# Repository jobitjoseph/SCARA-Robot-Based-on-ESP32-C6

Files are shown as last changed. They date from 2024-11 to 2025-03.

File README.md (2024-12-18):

# [DIY Scara Robot Based on RISC-V Architecture](https://circuitdigest.com/videos/scara-robotic-arm-using-esp32)
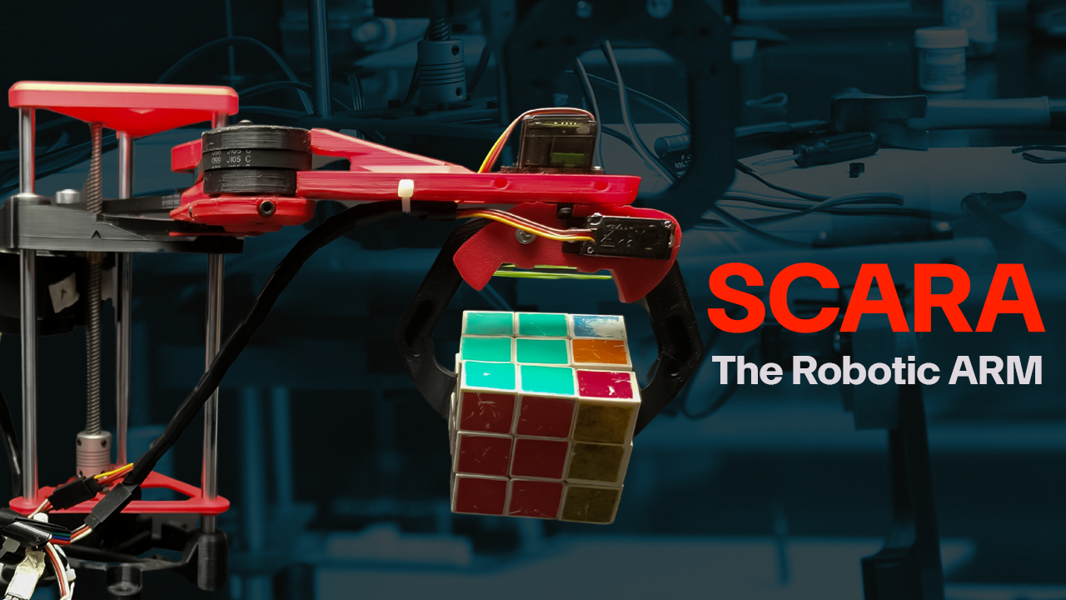
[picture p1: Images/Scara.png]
image_tooltip

<br>
A DIY SCARA (Selective Compliance Assembly Robot Arm) robot is a versatile, compact robotic arm designed for tasks requiring precision, such as assembly, sorting, and pick-and-place operations. As robotics becomes integral to modern industry and education, SCARA robots offer a practical and accessible way to explore automation, robotics programming, and motion control. This project combines affordability with high functionality, making it a valuable tool for learning and small-scale automation.
At the heart of the robot lies the ESP32-C6 WROOM module, a powerful microcontroller equipped with Wi-Fi and Bluetooth capabilities, ensuring seamless connectivity and control. The robot's motion is driven by NEMA 17 stepper motors, powered by TMC2209 drivers known for their smooth and efficient operation. Two SG90S servo motors handle the gripper, enabling precise manipulation of objects. The robot’s electronics are powered by a robust power system, featuring an LM2596-5 buck converter to step down a wide input voltage to 5V. This 5V rail is further regulated to 3.3V by an ADP7118AUJZ-3.3 low-noise CMOS LDO from Analog Devices, providing stable power to the ESP32-C6. Analog Devices’s MAX6899 supervisor IC ensures reliable boot-up of the system, while an onboard RGB LED offers visual feedback for status indications. The SCARA robot connects to a computer via a USB Type-C port, leveraging the ESP32-C6's native USB interface for streamlined communication. Control software, written in Python, provides an intuitive interface to operate the robot, featuring functions like direct control and a record-and-playback mode. This functionality allows users to program complex movements by recording and replaying actions with precision. The robot’s firmware is developed using the Arduino IDE, enabling customization and further development by hobbyists and professionals alike.

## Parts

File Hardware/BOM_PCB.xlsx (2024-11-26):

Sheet: Sheet1
Value | Footprint | Quantity | Manufacturer | Manufacturer Product Number | DigiKey Part Number | DigiKey Link
7pf | 0603 | 4 | Samsung Electro-Mechanics | CL10C070CB8NNNC | 1276-2137-1-ND | https://www.digikey.in/en/products/detail/samsung-electro-mechanics/CL10C070CB8NNNC/3887795
SDT30B100D1-13 | TO252_DIO | 2 | Diodes Incorporated | SDT30B100D1-13 | SDT30B100D1-13DICT-ND | https://www.digikey.in/en/products/detail/diodes-incorporated/SDT30B100D1-13/7667006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
ADP7118AUJZ-3.3-R7 | SOT95P280X100-5N | 4 | Analog Devices | ADP7118AUJZ-3.3-R7 | 505-ADP7118AUJZ-3.3-R7CT-ND | https://www.digikey.in/en/products/detail/analog-devices-inc/ADP7118AUJZ-3-3-R7/5056890
INA236BIDDFR | SOT65P280X110-8N | 2 | Texas Instruments | INA236BIDDFR | 296-INA236BIDDFRCT-ND | https://www.digikey.in/en/products/detail/texas-instruments/INA236BIDDFR/21298612
MCP6486T-E_OT | SOT95P280X145-5N | 2 | Microchip Technology | MCP6486T-E/OT | 150-MCP6486T-E/OTCT-ND | https://www.digikey.in/en/products/detail/microchip-technology/MCP6486T-E-OT/16623982
SP485REN-L_TR | SOIC127P600X175-8N | 2 | MaxLinear, Inc. | SP485REN-L/TR | 1016-SP485REN-L/TRCT-ND | https://www.digikey.in/en/products/detail/maxlinear-inc/SP485REN-L-TR/2471965
NTC 100K | NTC | 2 | Eaton - Electronics Division | NRSE105H3950B1H | 283-NRSE105H3950B1H-ND | https://www.digikey.in/en/products/detail/eaton-electronics-division/NRSE105H3950B1H/16909364
909R | 0603 | 4 | Panasonic Electronic Components | ERA-3AEB9090V | P909DBCT-ND | https://www.digikey.in/en/products/detail/panasonic-electronic-components/ERA-3AEB9090V/2026745
100R | 0603 | 4 | YAGEO | RT0603BRD07100RL | YAG1497CT-ND | https://www.digikey.in/en/products/detail/yageo/RT0603BRD07100RL/1072188
.1 10W | WSHP2818R1000FEB | 8 | Vishay Dale | WSHP2818R1000FEB | 541-WSHP2818R1000FEBCT-ND | https://www.digikey.in/en/products/detail/vishay-dale/WSHP2818R1000FEB/13983211
0R | 0603 | 2 | Stackpole Electronics Inc | RMCF0603ZT0R00 | RMCF0603ZT0R00CT-ND | https://www.digikey.in/en/products/detail/stackpole-electronics-inc/RMCF0603ZT0R00/1756908
20K | 0603 | 4 | Panasonic Electronic Components | ERJ-3EKF2002V | P20.0KHCT-ND | https://www.digikey.in/en/products/detail/panasonic-electronic-components/ERJ-3EKF2002V/196202
0.01R | 2 | 6 | Vishay Dale | WSHP2818R0100FEA | 541-3276-1-ND | https://www.digikey.in/en/products/detail/vishay-dale/WSHP2818R0100FEA/6605231
1.2K | 0603 | 2 | YAGEO | RC0603FR-071K2L | 311-1.20KHRCT-ND | https://www.digikey.in/en/products/detail/yageo/RC0603FR-071K2L/726852
STM32G071KBUx | QFN-32-1EP_5x5mm_P0.5mm_EP3.45x3.45mm | 1 | STMicroelectronics | STM32G071KBU3 | 497-STM32G071KBU3-ND | https://www.digikey.in/en/products/detail/stmicroelectronics/STM32G071KBU3/12337567
LTD-2601G | LTD-2601G_LTO | 2 | Lite-On Inc. | LTD-2601G | 160-1922-5-ND | https://www.digikey.in/en/products/detail/liteon/LTD-2601G/3199014
24CS32 | SOIC-8_3.9x4.9mm_P1.27mm | 2 | Microchip Technology | AT24CS32-SSHM-T | AT24CS32-SSHM-TCT-ND | https://www.digikey.in/en/products/detail/microchip-technology/AT24CS32-SSHM-T/4292102
32.768KHz | ECS327734BCTR | 2 | ECS Inc. | ECS-.327-7-34B-C-TR | XC1948CT-ND | https://www.digikey.in/en/products/detail/ecs-inc/ECS-327-7-34B-C-TR/3927420
ESP32-S3-WROOM-1 | ESP32-S3-WROOM-1 | 1 | Espressif Systems | ESP32-S3-WROOM-1-N16R8 | 1965-ESP32-S3-WROOM-1-N16R8CT-ND | https://www.digikey.in/en/products/detail/espressif-systems/ESP32-S3-WROOM-1-N16R8/16162642
INA226 | VSSOP-10_3x3mm_P0.5mm | 4 | Texas Instruments | INA226AIDGSR | 296-29034-1-ND | https://www.digikey.in/en/products/detail/texas-instruments/INA226AIDGSR/2687236
MCP6487 | SOIC127P600X175-8N | 2 | Microchip Technology | MCP6487T-E/SN | 150-MCP6487T-E/SNCT-ND | https://www.digikey.in/en/products/detail/microchip-technology/MCP6487T-E-SN/16624116
MAX6899AAZT+T | MAX6899AAZT+T | 2 | Analog Devices Inc./Maxim Integrated | MAX6899AAZT+T | MAX6899AAZT+TCT-ND | https://www.digikey.in/en/products/detail/analog-devices-inc-maxim-integrated/MAX6899AAZT-T/1781019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
ESP32-C6-WROOM-1 | ESP32-C6-WROOM-1 | 2 | Espressif Systems | ESP32-C6-WROOM-1-N8 | 1965-ESP32-C6-WROOM-1-N8CT-ND | https://www.digikey.in/en/products/detail/espressif-systems/ESP32-C6-WROOM-1-N8/17728866
NINA-B306-00B | NINA-B306-00B | 1 | u-blox | NINA-B306-00B | 672-NINA-B306-00BCT-ND | https://www.digikey.in/en/products/detail/u-blox/NINA-B306-00B/10257675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
LTC4065EDC | SON50P200X200X80-7N-D | 2 | Analog Devices Inc. | LTC4065EDC#TRMPBF | 505-LTC4065EDC#TRMPBFCT-ND | https://www.digikey.in/en/products/detail/analog-devices-inc/LTC4065EDC-TRMPBF/1115982
ADM7171ACPZ-3.3-R7 | SON50P300X300X80-9N-D | 2 | Analog Devices Inc. | ADM7171ACPZ-3.3-R7 | 505-ADM7171ACPZ-3.3-R7CT-ND | https://www.digikey.in/en/products/detail/analog-devices-inc/ADM7171ACPZ-3-3-R7/5011539
AP2127K-2.8 | SOT-23-5 | 3 | Diodes Incorporated | AP2127K-2.8TRG1 | AP2127K-2.8TRG1DICT-ND | https://www.digikey.in/en/products/detail/diodes-incorporated/AP2127K-2-8TRG1/4570641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
ESP32-S3-MINI-1U | ESP32-S2-MINI-1U | 3 | Espressif Systems | ESP32-S3-MINI-1-N4R2 | 1965-ESP32-S3-MINI-1-N4R2CT-ND | https://www.digikey.in/en/products/detail/espressif-systems/ESP32-S3-MINI-1-N4R2/22597234
AP2127K-1.8 | SOT-23-5 | 3 | Diodes Incorporated | AP2127K-1.8TRG1 | AP2127K-1.8TRG1DICT-ND | https://www.digikey.in/en/products/detail/diodes-incorporated/AP2127K-1-8TRG1/4470784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

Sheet: Sheet7
 |  |  | LCSC Part#
100nf | 0603 | 50 | C6119867
10uF | 0603 | 5 | C6119814
1uF | 0603 | 10 | C5189821
1nF | 0603 | 2 | C7503505
2.2uF | 0603 | 2 | C466773
2.2uF | 0402 | 2 | C729449
4.7u | C603 | 3 | C466777
4.7uF | C402 | 1 | C6119786
100nF | C402 | 3 | C6119799
330uF | CAP_J-V_10X10P5_RUB | 2 | C106663 | UGS1V331MP51016U | 4191-UGS1V331MP51016UCT-ND | https://www.digikey.in/en/products/detail/chinsan-elite/UGS1V331MP51016U/16497104
200R | TRIM_3296W-1-104 | 2 | C118939
10k | R402 | 2 | C2906885
2.2K | 0603 | 3 | C2907117
270K | 0603 | 3 | C2907133
27R | 0603 | 2 | C3017771
2K | R603 | 1 | C25590
470R | 0603 | 1 | C2907172
47K | 0603 | 1 | C2907173
100k | 0603 | 2 | C25201
10K | 0603 | 30 | C2930027
120R | 0603 | 1 | C2907096
1K | 0603 | 30 | C2907113
510R | R603 | 1 | C2907179
47uH | L_12x12mm_H8mm | 1 | C5127262
AO3401A | SOT-23 | 2 | C20628875
Barrel_Jack_Switch | BarrelJack_Kycon_KLDX-0202-xC_Horizontal | 2 | C7507454
18650 smd Holder |  | 2
3x4x2 tactile SW |  | 10 | C2888943
JST S2B-PH-SM4-TB | S2B-PH-SM4-TB | 2 | C295747
FLEX CONNECTOR, P=0.50MM, H=2.0M |  | 1 | C262669
Screw Terminal 5.08 1x02 |  | 2 | C8465
IRF540N | TO-220-3_Vertical | 4
LED Blue | 0603 | 4 | C965807
LED GREEN | 0805 | 25 | C7496832
LED Red | 0603 | 4 | C965799
MAX98357 module |  | 1
LM2596S-5 | TO-263-5_TabPin3 | 1 | C347421
MUR1560G | TO533P482X997X1956-2P | 2
S8050 | SOT-23 | 10 | C18221467
SS34 | D_SMA | 5 | C5249671
WS2812B-2020 | LED_WS2812B-2020_PLCC4_2.0x2.0mm | 2 | C965555
TP4056 Module |  | 1
USB C |  | 3 | C2927038
SK6812MINI-E_C5149201 |  | 150 | C5149201 | https://www.lcsc.com/product-detail/Light-Emitting-Diodes-LED_OPSCO-Optoelectronics-SK6812MINI-E_C5149201.html
5050 RGB LED |  | 4
1N4148WT | D_SOD-523 | 1 | C5381437
1.28 round display module |  | 1
MIC5219-3.3YM5 |  | 4 | C30197485
MPU6050 Module |  | 1
ESP32-S3 |  | 2 | C2913202
74HC595D |  | 2 | C2929943

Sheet: Sheet8
Value | Package | Qty | LCSC Part#
100nf | 0603 | 50 | C6119867
10uF | 0603 | 5 | C6119814
1uF | 0603 | 10 | C5189821
1nF | 0603 | 2 | C7503505
2.2uF | 0603 | 2 | C466773
2.2uF | 0402 | 2 | C729449
4.7u | C603 | 3 | C466777
4.7uF | C402 | 1 | C6119786
100nF | C402 | 3 | C6119799
330uF | CAP_J-V_10X10P5_RUB | 2 | C106663
200R | TRIM_3296W-1-104 | 2 | C118939
10k | R402 | 2 | C2906885
2.2K | 0603 | 3 | C2907117
270K | 0603 | 3 | C2907133
27R | 0603 | 2 | C3017771
2K | R603 | 1 | C25590
470R | 0603 | 1 | C2907172
47K | 0603 | 1 | C2907173
100k | 0603 | 2 | C25201
10K | 0603 | 30 | C2930027
120R | 0603 | 1 | C2907096
1K | 0603 | 30 | C2907113
510R | R603 | 1 | C2907179
47uH | L_12x12mm_H8mm | 1 | C5127262
AO3401A | SOT-23 | 2 | C20628875
JST S2B-PH-SM4-TB | S2B-PH-SM4-TB | 2 | C295747
LED Blue | 0603 | 4 | C965807
LED GREEN | 0805 | 25 | C7496832
LED Red | 0603 | 4 | C965799
LM2596S-5 | TO-263-5_TabPin3 | 1 | C347421
S8050 | SOT-23 | 10 | C18221467
SS34 | D_SMA | 5 | C5249671
WS2812B-2020 | LED_WS2812B-2020_PLCC4_2.0x2.0mm | 2 | C965555
USB C |  | 3 | C2927038
SK6812MINI-E_C5149201 |  | 150 | C5149201
1N4148WT | D_SOD-523 | 1 | C5381437
MIC5219-3.3YM5 |  | 4 | C30197485
ESP32-S3 |  | 2 | C2913202
74HC595D |  | 2 | C2929943
Barrel_Jack_Switch | BarrelJack_Kycon_KLDX-0202-xC_Horizontal | 2 | C7507454
3x4x2 tactile SW |  | 10 | C2888943
FLEX CONNECTOR, P=0.50MM, H=2.0M |  | 1 | C262669
Screw Terminal 5.08 1x02 |  | 2 | C8465
TO4056 |  | 2 | C382139
18650 smd Holder |  | 2 | https://robu.in/product/18650-battery-holder-smd-smt/
MAX98357 module |  | 1 | https://robu.in/product/max98357aetet-maxim-integrated-products/
MAX4466 Microphone Module |  | 3 | https://robu.in/product/max4466-electret-microphone-amplifier-with-adjustable-gain-module/
IRF540N | TO-220-3_Vertical | 4 | https://etstore.in/index.php/product/1140/
MPU6050 Module |  | 2 | https://etstore.in/index.php/product/mpu6050-module-3-accelerometer-for-arduino-gy-521-mpu-6050/
MUR1560G | TO533P482X997X1956-2P | 2 | https://etstore.in/index.php/product/mur1560g-ultrafast-diode-15a-600v/
5050 RGB LED |  | 4 | https://etstore.in/index.php/product/1788/
LM1117 3.3V |  | 2 | https://etstore.in/index.php/product/ld1117ag-3-3v-utc-sot223-5v-1a-ldo-voltage-regulator/
1.28 round display module |  | 1 | https://rarecomponents.com/store/1-28inch-lcd-module

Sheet: Sheet6
IC1 | TP4056 | SOIC127P600X175-9N | 1 | 3PEAK | TPB4056B2X-ES1R | 5503-TPB4056B2X-ES1RCT-ND | https://www.digikey.in/en/products/detail/3peak/TPB4056B2X-ES1R/22228451
J1 | USB_C_Receptacle_USB2.0 | USB_C_Receptacle_HRO_TYPE-C-31-M-12 | 1 | Assmann WSW Components | A-USBC-20F0-EA-GSR11 | 123-A-USBC-20F0-EA-GSR11CT-ND | https://www.digikey.in/en/products/detail/assmann-wsw-components/A-USBC-20F0-EA-GSR11/18734925
J3 | USB_C_Receptacle_USB2.0 | USB_C_Receptacle_HRO_TYPE-C-31-M-12 | 1 | Assmann WSW Components | A-USBC-20F0-EA-GSR11 | 123-A-USBC-20F0-EA-GSR11CT-ND | https://www.digikey.in/en/products/detail/assmann-wsw-components/A-USBC-20F0-EA-GSR11/18734925
Designator | Value | Footprint | Quantity | Manufacturer | Manufacturer Product Number | DigiKey Part Number | DigiKey Link
D1, D2 | WS2812B-2020 | LED_WS2812B-2020_PLCC4_2.0x2.0mm | 2

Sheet: Cell Grading
Designator | Value | Footprint | Quantity | Manufacturer | Manufacturer Product Number | DigiKey Part Number | DigiKey Link
BT1 | Battery_Cell | BAT_1042 | 1 | Keystone Electronics | 1042 | 36-1042-ND | https://www.digikey.in/en/products/detail/keystone-electronics/1042/2745668
C1 | 10uF | 0603 | 1 | Cal-Chip Electronics, Inc. | GMC10X5R106M10NT | 4713-GMC10X5R106M10NTCT-ND | https://www.digikey.in/en/products/detail/cal-chip-electronics-inc/GMC10X5R106M10NT/18151101
C2 | 2.2uF | 0603 | 1 | Samsung Electro-Mechanics | CL10B225KP8NNNC | 1276-1134-1-ND | https://www.digikey.in/en/products/detail/samsung-electro-mechanics/CL10B225KP8NNNC/3886792
C4, C5 | 7pf | 0603 | 2 | Samsung Electro-Mechanics | CL10C070CB8NNNC | 1276-2137-1-ND | https://www.digikey.in/en/products/detail/samsung-electro-mechanics/CL10C070CB8NNNC/3887795
C6, C7, C8, C9 | 100nF | 0603 | 4 | YAGEO | CC0603KRX7R7BB104 | 311-1088-1-ND | https://www.digikey.in/en/products/detail/yageo/CC0603KRX7R7BB104/302822
D1 | SDT30B100D1-13 | TO252_DIO | 1 | Diodes Incorporated | SDT30B100D1-13 | SDT30B100D1-13DICT-ND | https://www.digikey.in/en/products/detail/diodes-incorporated/SDT30B100D1-13/7667006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
IC1 | TP4056 | SOIC127P600X175-9N | 1 | 3PEAK | TPB4056B2X-ES1R | 5503-TPB4056B2X-ES1RCT-ND | https://www.digikey.in/en/products/detail/3peak/TPB4056B2X-ES1R/22228451
IC2 | ADP7118AUJZ-3.3-R7 | SOT95P280X100-5N | 1 | Analog Devices | ADP7118AUJZ-3.3-R7 | 505-ADP7118AUJZ-3.3-R7CT-ND | https://www.digikey.in/en/products/detail/analog-devices-inc/ADP7118AUJZ-3-3-R7/5056890
IC3 | INA236BIDDFR | SOT65P280X110-8N | 1 | Texas Instruments | INA236BIDDFR | 296-INA236BIDDFRCT-ND | https://www.digikey.in/en/products/detail/texas-instruments/INA236BIDDFR/21298612
IC4 | MCP6486T-E_OT | SOT95P280X145-5N | 1 | Microchip Technology | MCP6486T-E/OT | 150-MCP6486T-E/OTCT-ND | https://www.digikey.in/en/products/detail/microchip-technology/MCP6486T-E-OT/16623982
IC5 | SP485REN-L_TR | SOIC127P600X175-8N | 1 | MaxLinear, Inc. | SP485REN-L/TR | 1016-SP485REN-L/TRCT-ND | https://www.digikey.in/en/products/detail/maxlinear-inc/SP485REN-L-TR/2471965
J1 | Barrel_Jack_Switch | BarrelJack_Kycon_KLDX-0202-xC_Horizontal | 1 | GlobTek, Inc. | G-1005B | 1939-G-1005B-ND | https://www.digikey.in/en/products/detail/globtek-inc/G-1005B/16515799
J2, J3 | Conn_01x02 | JST_PH_S2B-PH-SM4-TB_1x02-1MP_P2.00mm_Horizontal | 2 | JST Sales America Inc. | S2B-PH-SM4-TB | 455-S2B-PH-SM4-TBCT-ND | https://www.digikey.in/en/products/detail/jst-sales-america-inc/S2B-PH-SM4-TB/926655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
LED1 | LED Red | 0603 | 1 | Harvatek Corporation | B1911USD-20D000114U1930 | 3147-B1911USD-20D000114U1930CT-ND | https://www.digikey.in/en/products/detail/harvatek-corporation/B1911USD-20D000114U1930/15519991
LED2 | LED Blue | 0603 | 1 | Harvatek Corporation | F1961NB--20C001714U1930 | 3147-F1961NB--20C001714U1930-ND | https://www.digikey.in/en/products/detail/harvatek-corporation/F1961NB-20C001714U1930/16341596
Q1, Q3 | S8050 | SOT-23 | 2 | Micro Commercial Co | MMS8050-H-TP | 353-MMS8050-H-TPCT-ND | https://www.digikey.in/en/products/detail/micro-commercial-co/MMS8050-H-TP/7320084
Q2, Q4 | IRF540N | TO-220-3_Vertical | 2 | Vishay Siliconix | IRL540PBF | IRL540PBF-ND | https://www.digikey.in/en/products/detail/vishay-siliconix/IRL540PBF/812025
R1, R2 | 1.3K | 0603 | 2 | YAGEO | RC0603JR-071K3L | 311-1.3KGRCT-ND | https://www.digikey.in/en/products/detail/yageo/RC0603JR-071K3L/726686
R10, R11, R26, R33, R34, R35, R6, R7 | 10K | 0603 | 8 | Stackpole Electronics Inc | RMCF0603JT10K0 | RMCF0603JT10K0CT-ND | https://www.digikey.in/en/products/detail/stackpole-electronics-inc/RMCF0603JT10K0/1758104
R12 | NTC 100K | NTC | 1 | Eaton - Electronics Division | NRSE105H3950B1H | 283-NRSE105H3950B1H-ND | https://www.digikey.in/en/products/detail/eaton-electronics-division/NRSE105H3950B1H/16909364
R13, R14, R15, R16, R17, R18, R19, R20, R21, R23, R30, R31, R32, R39, R8, R9 | 1K | 0603 | 15 | YAGEO | RC0603FR-071KL | 311-1.00KHRCT-ND | https://www.digikey.in/en/products/detail/yageo/RC0603FR-071KL/726843
R22 | 909R | 0603 | 1 | Panasonic Electronic Components | ERA-3AEB9090V | P909DBCT-ND | https://www.digikey.in/en/products/detail/panasonic-electronic-components/ERA-3AEB9090V/2026745
R24, R40 | 270K | 0603 | 2 | YAGEO | RC0603FR-07270KL | 311-270KHRCT-ND | https://www.digikey.in/en/products/detail/yageo/RC0603FR-07270KL/727104
R25 | 100R | 0603 | 1 | YAGEO | RT0603BRD07100RL | YAG1497CT-ND | https://www.digikey.in/en/products/detail/yageo/RT0603BRD07100RL/1072188
R27, R29 | 2.2K | 0603 | 2 | YAGEO | RC0603FR-072K2L | 311-2.20KHRCT-ND | https://www.digikey.in/en/products/detail/yageo/RC0603FR-072K2L/727016
R28, R4, R41 | .01 5W | WSHP2818R1000FEB | 3 | Vishay Dale | WSHP2818R1000FEB | 541-WSHP2818R1000FEBCT-ND | https://www.digikey.in/en/products/detail/vishay-dale/WSHP2818R1000FEB/13983211
R3 | 0R | 0603 | 1 | Stackpole Electronics Inc | RMCF0603ZT0R00 | RMCF0603ZT0R00CT-ND | https://www.digikey.in/en/products/detail/stackpole-electronics-inc/RMCF0603ZT0R00/1756908
R36, R37 | 20K | 0603 | 2 | Panasonic Electronic Components | ERJ-3EKF2002V | P20.0KHCT-ND | https://www.digikey.in/en/products/detail/panasonic-electronic-components/ERJ-3EKF2002V/196202
R38 | 120R | 0603 | 1 | Stackpole Electronics Inc | RMCF0603FT120R | RMCF0603FT120RCT-ND | https://www.digikey.in/en/products/detail/stackpole-electronics-inc/RMCF0603FT120R/1761221
R5 | 0.01R | WSHP2818R0100FEA | 1 | Vishay Dale | WSHP2818R0100FEA | 541-3276-1-ND | https://www.digikey.in/en/products/detail/vishay-dale/WSHP2818R0100FEA/6605231
RV1 | 200R | TRIM_3296W-1-104 | 1 | Bourns Inc. | 3296Y-1-201LF | 3296Y-201LF-ND | https://www.digikey.in/en/products/detail/bourns-inc/3296Y-1-201LF/1088089
Rprog1 | 1.2K | 0603 | 1 | YAGEO | RC0603FR-071K2L | 311-1.20KHRCT-ND | https://www.digikey.in/en/products/detail/yageo/RC0603FR-071K2L/726852
SW1 | RST | Tactile 3x4x2mm TS-A010 | 1 | CIT Relay and Switch | CS1213AGF160 | 2449-CS1213AGF160CT-ND | https://www.digikey.in/en/products/detail/cit-relay-and-switch/CS1213AGF160/16607723
U1 | STM32G071KBUx | QFN-32-1EP_5x5mm_P0.5mm_EP3.45x3.45mm | 1 | STMicroelectronics | STM32G071KBU3 | 497-STM32G071KBU3-ND | https://www.digikey.in/en/products/detail/stmicroelectronics/STM32G071KBU3/12337567
U2 | LTD-2601G | LTD-2601G_LTO | 1 | Lite-On Inc. | LTD-2601G | 160-1922-5-ND | https://www.digikey.in/en/products/detail/liteon/LTD-2601G/3199014
U3 | 24CS32 | SOIC-8_3.9x4.9mm_P1.27mm | 1 | Microchip Technology | AT24CS32-SSHM-T | AT24CS32-SSHM-TCT-ND | https://www.digikey.in/en/products/detail/microchip-technology/AT24CS32-SSHM-T/4292102
Y1 | 32.768KHz | ECS327734BCTR | 1 | ECS Inc. | ECS-.327-7-34B-C-TR | XC1948CT-ND | https://www.digikey.in/en/products/detail/ecs-inc/ECS-327-7-34B-C-TR/3927420

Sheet: ESP32 Smart Glass
Designator | Value | Footprint | Quantity | Manufacturer | Manufacturer Product Number | DigiKey Part Number | DigiKey Link
C1, C2, C4 | 4.7u | C603 | 3 | Samsung Electro-Mechanics | CL10A475KP8NNNC | 1276-1044-1-ND | https://www.digikey.in/en/products/detail/samsung-electro-mechanics/CL10A475KP8NNNC/3886702
C12 | 2.2uF | C603 | 1 | Samsung Electro-Mechanics | CL10B225KP8NNNC | 1276-1134-1-ND | https://www.digikey.in/en/products/detail/samsung-electro-mechanics/CL10B225KP8NNNC/3886792
C13 | 100nF | C603 | 1 | YAGEO | CC0603KRX7R7BB104 | 311-1088-1-ND | https://www.digikey.in/en/products/detail/yageo/CC0603KRX7R7BB104/302822
C20, C22, C24 | 100nF | C402 | 3 | Murata Electronics | GRM155R71C104KA88J | 490-6328-1-ND | https://www.digikey.in/en/products/detail/murata-electronics/GRM155R71C104KA88J/2610892
C21 | 4.7uF | C402 | 1 | Samsung Electro-Mechanics | CL05A475MP5NRNC | 1276-1482-1-ND | https://www.digikey.in/en/products/detail/samsung-electro-mechanics/CL05A475MP5NRNC/3887140
C23 | 2.2uF | C402 | 1 | Samsung Electro-Mechanics | CL05A225MP5NSNC | 1276-1467-1-ND | https://www.digikey.in/en/products/detail/samsung-electro-mechanics/CL05A225MP5NSNC/3887125
C25, C26, C27, C28 | 1uF | C603 | 4 | YAGEO | CC0603KRX7R7BB105 | 311-1446-1-ND | https://www.digikey.in/en/products/detail/yageo/CC0603KRX7R7BB105/2833611
C3 | 1nF | C603 | 1 | KEMET | C0603C102K5RAC7867 | 399-C0603C102K5RAC7867CT-ND | https://www.digikey.in/en/products/detail/kemet/C0603C102K5RAC7867/411081
D1, D2 | WS2812B-2020 | LED_WS2812B-2020_PLCC4_2.0x2.0mm | 2
D4 | 1N4148WT | D_SOD-523 | 1 | ANBON SEMICONDUCTOR (INT'L) LIMITED | 1N4148WT | 4530-1N4148WTCT-ND | https://www.digikey.in/en/products/detail/anbon-semiconductor-int-l-limited/1N4148WT/17284364
IC1 | LTC4065EDC | SON50P200X200X80-7N-D | 1 | Analog Devices Inc. | LTC4065EDC#TRMPBF | 505-LTC4065EDC#TRMPBFCT-ND | https://www.digikey.in/en/products/detail/analog-devices-inc/LTC4065EDC-TRMPBF/1115982
IC2 | ADM7171ACPZ-3.3-R7 | SON50P300X300X80-9N-D | 1 | Analog Devices Inc. | ADM7171ACPZ-3.3-R7 | 505-ADM7171ACPZ-3.3-R7CT-ND | https://www.digikey.in/en/products/detail/analog-devices-inc/ADM7171ACPZ-3-3-R7/5011539
IC5 | MAX98357AETE+T | QFN50P300X300X80-17N | 1 | Analog Devices Inc./Maxim Integrated | MAX98357AETE+T | MAX98357AETE+TCT-ND | https://www.digikey.in/en/products/detail/analog-devices-inc-maxim-integrated/MAX98357AETE-T/4936122
J2 | 10118194-0001LF | AMPHENOL_10118194-0001LF | 1 | Amphenol ICC (FCI) | 10118194-0001LF | 609-4618-1-ND | https://www.digikey.in/en/products/detail/amphenol-icc-(fci)/10118194-0001LF/2785382?productid=2785382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
J5 | Conn_01x24 | TE_2-1734839-4_1x24-1MP_P0.5mm_Horizontal | 1 | Amphenol ICC (FCI) | F33Z-1A7Q1-E8C24 | 609-F33Z-1A7Q1-E8C24CT-ND | https://www.digikey.in/en/products/detail/amphenol-cs-fci/F33Z-1A7Q1-E8C24/20415093
LED1 | Red | LED603 | 1 | Harvatek Corporation | B1911USD-20D000114U1930 | 3147-B1911USD-20D000114U1930CT-ND | https://www.digikey.in/en/products/detail/harvatek-corporation/B1911USD-20D000114U1930/15519991
R1 | 510R | R603 | 1 | YAGEO | RC0603FR-07510RL | 311-510HRCT-ND | https://www.digikey.in/en/products/detail/yageo/RC0603FR-07510RL/727285
R10, R9 | 10k | R402 | 2 | YAGEO | RC0402JR-0710KL | 311-10KJRCT-ND | https://www.digikey.in/en/products/detail/yageo/RC0402JR-0710KL/726418
R12 | 0R | R603 | 1 | Stackpole Electronics Inc | RMCF0603ZT0R00 | RMCF0603ZT0R00CT-ND | https://www.digikey.in/en/products/detail/stackpole-electronics-inc/RMCF0603ZT0R00/1756908
R2 | 2K | R603 | 1 | Panasonic Electronic Components | ERJ-3EKF2001V | P2.00KHCT-ND | https://www.digikey.in/en/products/detail/panasonic-electronic-components/ERJ-3EKF2001V/196183
R3 | 100K | R603 | 1 | Panasonic Electronic Components | ERJ-3EKF1003V | P100KHCT-ND | https://www.digikey.in/en/products/detail/panasonic-electronic-components/ERJ-3EKF1003V/196075
R4, R5 | 10k | R603 | 2 | Stackpole Electronics Inc | RMCF0603JT10K0 | RMCF0603JT10K0CT-ND | https://www.digikey.in/en/products/detail/stackpole-electronics-inc/RMCF0603JT10K0/1758104
SW1 | K3-1280S-F1 | slide switch spdt | 1 | Nidec Components Corporation | CUS-12TB | 563-1102-1-ND | https://www.digikey.in/en/products/detail/nidec-components-corporation/CUS-12TB/1124222
SW2, SW3 | RST | Tactile 3x4x2mm TS-A010 | 2 | CIT Relay and Switch | CS1213AGF160 | 2449-CS1213AGF160CT-ND | https://www.digikey.in/en/products/detail/cit-relay-and-switch/CS1213AGF160/16607723
U2 | AP2127K-2.8 | SOT-23-5 | 1 | Diodes Incorporated | AP2127K-2.8TRG1 | AP2127K-2.8TRG1DICT-ND | https://www.digikey.in/en/products/detail/diodes-incorporated/AP2127K-2-8TRG1/4570641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
U3 | ESP32-S3-MINI-1U | ESP32-S2-MINI-1U | 1 | Espressif Systems | ESP32-S3-MINI-1-N4R2 | 1965-ESP32-S3-MINI-1-N4R2CT-ND | https://www.digikey.in/en/products/detail/espressif-systems/ESP32-S3-MINI-1-N4R2/22597234
U4 | AP2127K-1.8 | SOT-23-5 | 1 | Diodes Incorporated | AP2127K-1.8TRG1 | AP2127K-1.8TRG1DICT-ND | https://www.digikey.in/en/products/detail/diodes-incorporated/AP2127K-1-8TRG1/4470784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

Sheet: MPPT
Designator | Value | Footprint | Quantity | Value | LCSC Part # | Value | LCSC Part #
BT1 | Battery_Cell | BatteryHolder_Keystone_1042_1x18650 | 1 | Manufacturer | Manufacturer Product Number | DigiKey Part Number | DigiKey Link
C11, C13, C15 | 10uf | 0603 | 3 | Cal-Chip Electronics, Inc. | GMC10X5R106M10NT | 4713-GMC10X5R106M10NTCT-ND | https://www.digikey.in/en/products/detail/cal-chip-electronics-inc/GMC10X5R106M10NT/18151101
C14 | 2.2uF | 0805 | 1 | Murata Electronics | GRM21BR71E225KE11L | 490-14467-1-ND | https://www.digikey.in/en/products/detail/murata-electronics/GRM21BR71E225KE11L/6606096
C19 | 1uf | 0603 | 1 | YAGEO | CC0603KRX7R7BB105 | 311-1446-1-ND | https://www.digikey.in/en/products/detail/yageo/CC0603KRX7R7BB105/2833611
C7, C8, C20 | 100n | 0603 | 3 | YAGEO | CC0603KRX7R7BB104 | 311-1088-1-ND | https://www.digikey.in/en/products/detail/yageo/CC0603KRX7R7BB104/302822
D6 | SS34 | D_SMA | 1 | Comchip Technology | SS34-HF | 641-2115-1-ND | https://www.digikey.in/en/products/detail/comchip-technology/SS34-HF/10279693
D5 | MUR1560G | TO533P482X997X1956-2P | 1 | onsemi | MUR1560G | MUR1560GOS-ND | https://www.digikey.in/en/products/detail/onsemi/MUR1560G/919902?s=N4IgTCBcDaILIFUBKBGArANgAwHEQF0BfIA
J1 | USB_C_Receptacle_USB2.0 | USB_C_Receptacle_HRO_TYPE-C-31-M-12 | 1 | Assmann WSW Components | A-USBC-20F0-EA-GSR11 | 123-A-USBC-20F0-EA-GSR11CT-ND | https://www.digikey.in/en/products/detail/assmann-wsw-components/A-USBC-20F0-EA-GSR11/18734925
J4 | Conn_01x02 | TerminalBlock_bornier-2_P5.08mm | 1 | Phoenix Contact | 5442206 | 277-12547-ND | https://www.digikey.in/en/products/detail/phoenix-contact/5442206/4390264
LED1 | POW_LED | 0603 | 1 | Harvatek Corporation | B1911USD-20D000114U1930 | 3147-B1911USD-20D000114U1930CT-ND | https://www.digikey.in/en/products/detail/harvatek-corporation/B1911USD-20D000114U1930/15519991
LED2 | 150505M173300 | 150505M173300 | 1 | Harvatek Corporation | T3A83RGB-20C001011U1930 | 3147-T3A83RGB-20C001011U1930CT-ND | https://www.digikey.in/en/products/detail/harvatek-corporation/T3A83RGB-20C001011U1930/21738598
Q1,U9 | AO3401A | SOT-23 | 2 | Alpha & Omega Semiconductor Inc. | AO3401A | 785-1001-1-ND | https://www.digikey.in/en/products/detail/alpha-omega-semiconductor-inc/AO3401/8573943
Q2 | S8050 | SOT-23 | 1 | Micro Commercial Co | MMS8050-H-TP | 353-MMS8050-H-TPCT-ND | https://www.digikey.in/en/products/detail/micro-commercial-co/MMS8050-H-TP/7320084
Q3 | IRF540N | TO-220-3_Vertical | 1 | Vishay Siliconix | IRL540PBF | IRL540PBF-ND | https://www.digikey.in/en/products/detail/vishay-siliconix/IRL540PBF/812025
R22 | 0.1R | WSHP2818R1000FEB | 1 | Vishay Dale | WSHP2818R1000FEB | 541-WSHP2818R1000FEBCT-ND | https://www.digikey.in/en/products/detail/vishay-dale/WSHP2818R1000FEB/13983211
R11, R12, R13, R18, R23, R24, R32, R33, R7, R8, R9 | 10K | 0603 | 11 | Stackpole Electronics Inc | RMCF0603JT10K0 | RMCF0603JT10K0CT-ND | https://www.digikey.in/en/products/detail/stackpole-electronics-inc/RMCF0603JT10K0/1758104
R14, R16, R27, R28, R29 | 1K | 0603 | 5 | YAGEO | RC0603FR-071KL | 311-1.00KHRCT-ND | https://www.digikey.in/en/products/detail/yageo/RC0603FR-071KL/726843
R15 | 909R | 0603 | 1 | Panasonic Electronic Components | ERA-3AEB9090V | P909DBCT-ND | https://www.digikey.in/en/products/detail/panasonic-electronic-components/ERA-3AEB9090V/2026745
R17 | 100R | 0603 | 1 | YAGEO | RT0603BRD07100RL | YAG1497CT-ND | https://www.digikey.in/en/products/detail/yageo/RT0603BRD07100RL/1072188
R19 | 2.2K | 0603 | 1 | YAGEO | RC0603FR-072K2L | 311-2.20KHRCT-ND | https://www.digikey.in/en/products/detail/yageo/RC0603FR-072K2L/727016
R20 | 270K | 0603 | 1 | YAGEO | RC0603FR-07270KL | 311-270KHRCT-ND | https://www.digikey.in/en/products/detail/yageo/RC0603FR-07270KL/727104
R21 | 100K | 0603 | 1 | Panasonic Electronic Components | ERJ-3EKF1003V | P100KHCT-ND | https://www.digikey.in/en/products/detail/panasonic-electronic-components/ERJ-3EKF1003V/196075
R10, R6 | .01 5W | WSHP2818R0100FEA | 2 | Vishay Dale | WSHP2818R0100FEA | 541-3276-1-ND | https://www.digikey.in/en/products/detail/vishay-dale/WSHP2818R0100FEA/6605231
R25, R26 | 27R | 0603 | 2 | YAGEO | RC0603JR-0727RL | 311-27GRCT-ND | https://www.digikey.in/en/products/detail/yageo/RC0603JR-0727RL/726751
R30 | 470R | 0603 | 1 | Panasonic Electronic Components | ERA-3AEB471V | P470DBCT-ND | https://www.digikey.in/en/products/detail/panasonic-electronic-components/ERA-3AEB471V/1465846
RV1 | 200R | TRIM_3296W-1-104 | 1 | Bourns Inc. | 3296Y-1-201LF | 3296Y-201LF-ND | https://www.digikey.in/en/products/detail/bourns-inc/3296Y-1-201LF/1088089
SW1, SW2 | Boot | Tactile 3x4x2mm TS-A010 | 2 | CIT Relay and Switch | CS1213AGF160 | 2449-CS1213AGF160CT-ND | https://www.digikey.in/en/products/detail/cit-relay-and-switch/CS1213AGF160/16607723
U10 | AMS1117-3.3 | SOT-223-3_TabPin2 | 1 | Diotec Semiconductor | LDI1117-3.3H | 4878-LDI1117-3.3HCT-ND | https://www.digikey.in/en/products/detail/diotec-semiconductor/LDI1117-3-3H/13154408
U12 | ESP32-S3-WROOM-1 | ESP32-S3-WROOM-1 | 1 | Espressif Systems | ESP32-S3-WROOM-1-N16R8 | 1965-ESP32-S3-WROOM-1-N16R8CT-ND | https://www.digikey.in/en/products/detail/espressif-systems/ESP32-S3-WROOM-1-N16R8/16162642
U3, U4 | INA226 | VSSOP-10_3x3mm_P0.5mm | 2 | Texas Instruments | INA226AIDGSR | 296-29034-1-ND | https://www.digikey.in/en/products/detail/texas-instruments/INA226AIDGSR/2687236
U5 | MCP6487 | SOIC127P600X175-8N | 1 | Microchip Technology | MCP6487T-E/SN | 150-MCP6487T-E/SNCT-ND | https://www.digikey.in/en/products/detail/microchip-technology/MCP6487T-E-SN/16624116
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

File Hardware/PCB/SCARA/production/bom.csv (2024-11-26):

Designator | Footprint | Quantity | Value | LCSC Part #
C1, C2 | CAP_J-V_10X10P5_RUB | 2 | 330uF
C10, C5 | 0805 | 2 | 10uF
C11, C7, C8, C9 | 0603 | 4 | 0.1uF
C3 | 0603 | 1 | 2.2uF
C4 | 0603 | 1 | NC
D1, D3 | D_SMA | 2 | SS34
D2 | 0805 | 1 | LED
IC1 | SOT95P280X100-5N | 1 | ADP7118AUJZ-3.3-R7
J1 | TerminalBlock_Phoenix_PT-1,5-2-5.0-H_1x02_P5.00mm_Horizontal | 1 | Screw_Terminal_2_P5.00mm
J10, J4, J6, J8 | PinHeader_2x03_P2.54mm_Vertical | 4 | Conn_02x03_Top_Bottom
J11, J5, J7, J9 | JST_XH_B4B-XH-AM_1x04_P2.50mm_Vertical | 4 | Conn_01x04
J12, J13, J14, J15, J16 | JST_XH_B3B-XH-AM_1x03_P2.50mm_Vertical | 5 | Conn_01x03
J17 | JST_EH_B4B-EH-A_1x04_P2.50mm_Vertical | 1 | Conn_01x04
J2 | BarrelJack_Kycon_KLDX-0202-xC_Horizontal | 1 | Barrel_Jack_Switch
J3 | USB_C_Receptacle_HRO_TYPE-C-31-M-12 | 1 | USB_C_Receptacle_USB2.0
L1 | L_12x12mm_H8mm | 1 | 47uH
LED1 | 150505M173300 | 1 | 150505M173300
R1 | 0603 | 1 | 0
R10, R11, R12, R13, R14, R15, R16, R17, R6, R7, R8 | 0603 | 11 | 1K
R18, R19, R2, R20, R21, R4, R5, R9 | 0603 | 8 | 10K
R3 | 0603 | 1 | 47K
SW1 | Tactile 3x4x2mm TS-A010 | 1 | RST
SW2 | Tactile 3x4x2mm TS-A010 | 1 | BOOT
U1 | TO-263-5_TabPin3 | 1 | LM2596S-5
U2 | MAX6899AAZT+T | 1 | MAX6899AAZT+T
U3 | ESP32-C6-WROOM-1 | 1 | ESP32-C6-WROOM-1
U4, U5, U6, U7 | MODULE_TMC2209_SILENTSTEPSTICK | 4 | TMC2209_SILENTSTEPSTICK

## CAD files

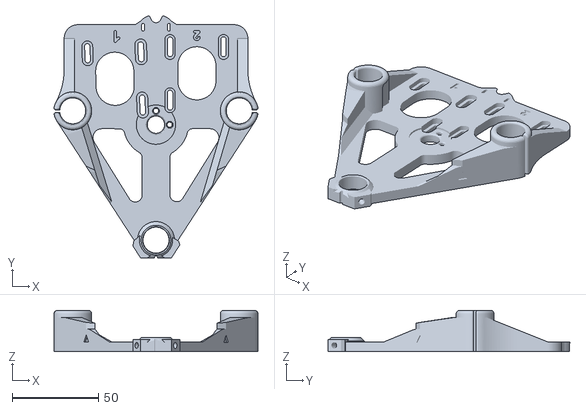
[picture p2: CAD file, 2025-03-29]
3D Models/untitledz-base-v10.stl
118.4 x 140.4 x 24.0

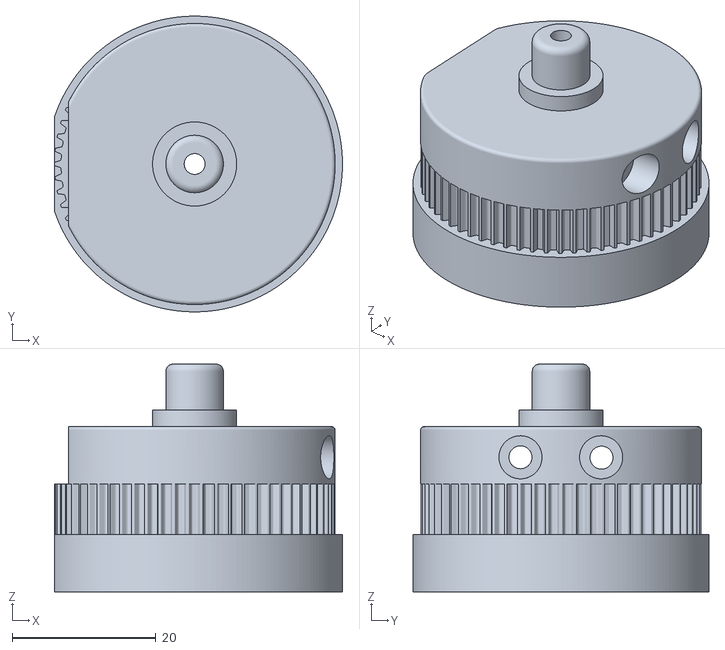
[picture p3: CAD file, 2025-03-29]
3D Models/untitledarm-hub-v11.stl
40.1 x 41.2 x 31.7

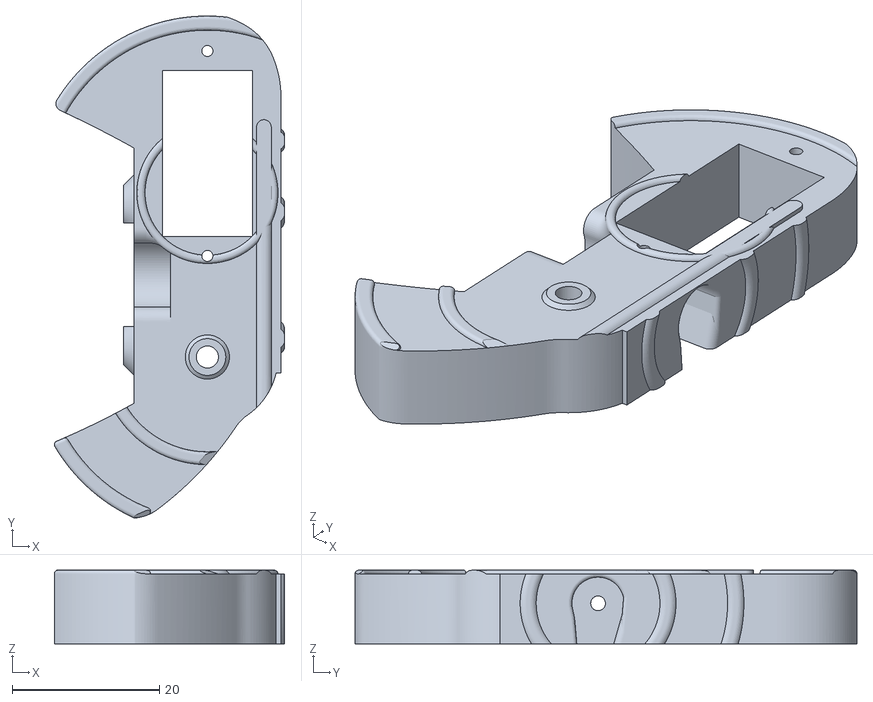
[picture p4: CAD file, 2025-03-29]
3D Models/untitledgripper-base-v10.stl
31.3 x 68.2 x 10.0

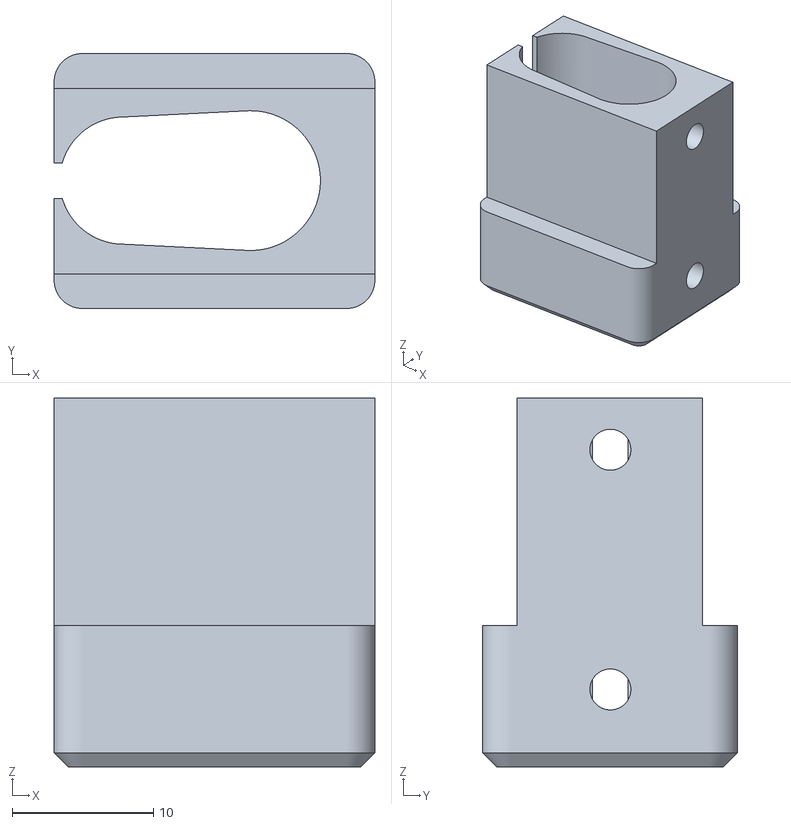
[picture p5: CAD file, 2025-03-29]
3D Models/untitledpen-holder-v10.stl
22.7 x 18.0 x 26.1

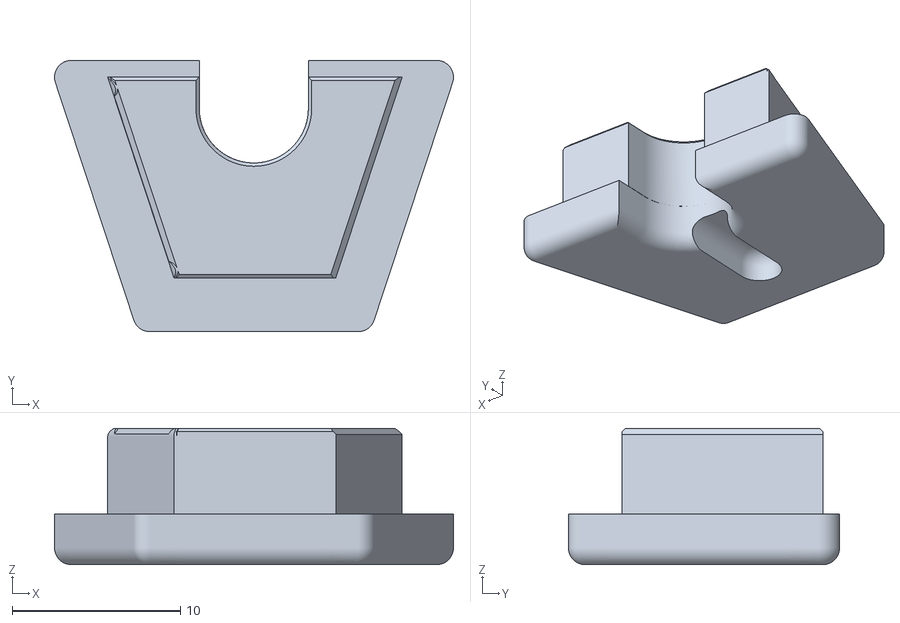
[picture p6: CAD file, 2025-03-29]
3D Models/untitledcables-cap-v10.stl
23.7 x 16.1 x 8.10

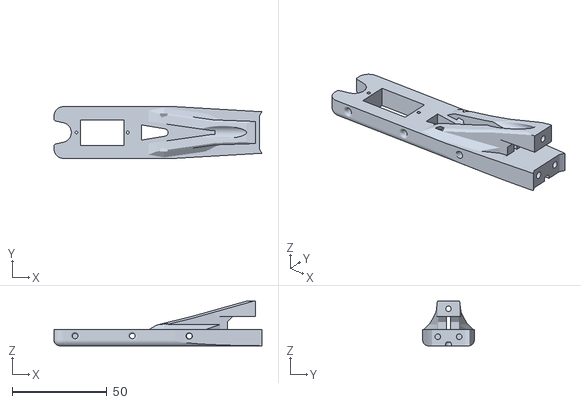
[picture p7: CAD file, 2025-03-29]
3D Models/untitledfoream-v10.stl
109.6 x 27.2 x 23.5

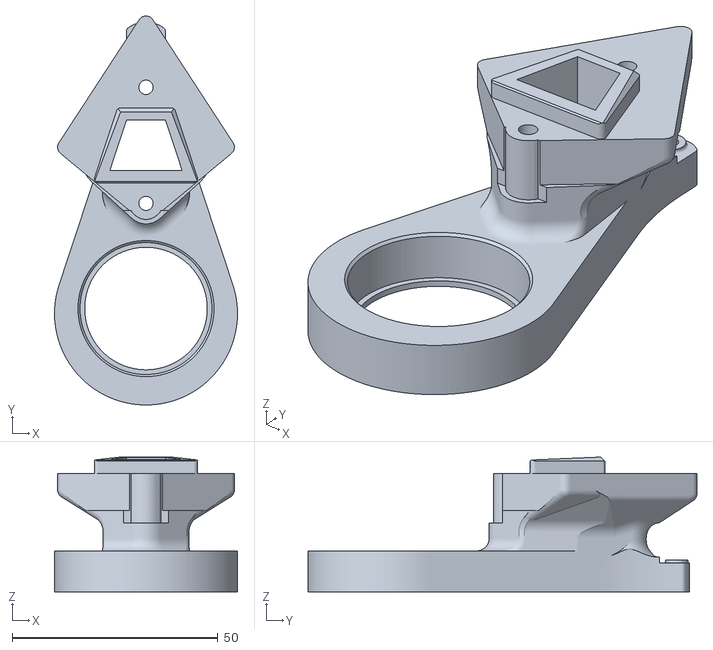
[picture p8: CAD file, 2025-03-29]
3D Models/untitledarm-bottom-v10.stl
44.5 x 94.6 x 32.8

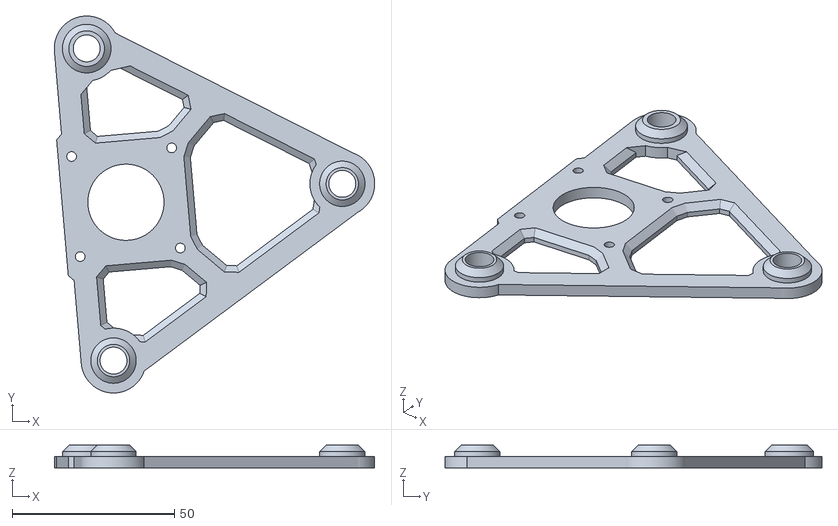
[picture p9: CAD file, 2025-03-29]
3D Models/untitledmotors-triangle-v10.stl
98.9 x 116.3 x 7.00

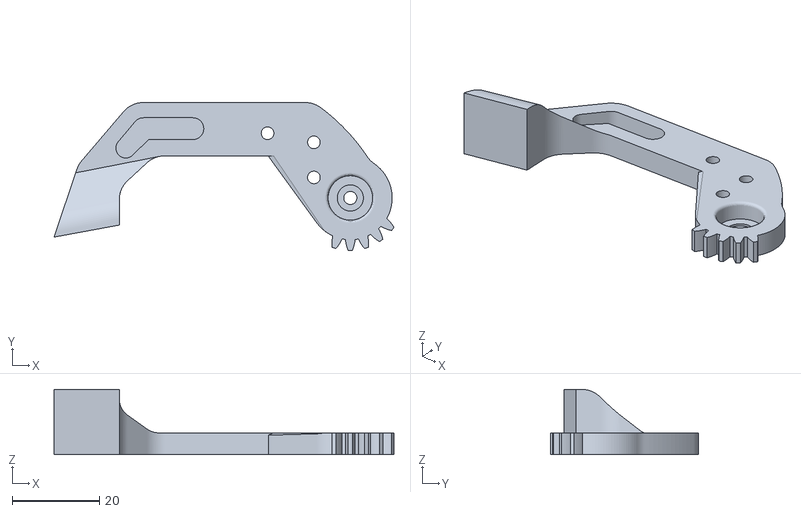
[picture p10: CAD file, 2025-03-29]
3D Models/untitledgripper-nails-v10_001.stl
78.0 x 34.0 x 15.0

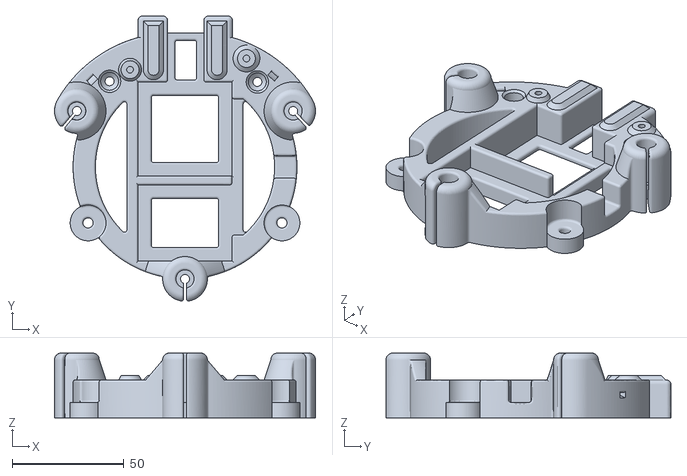
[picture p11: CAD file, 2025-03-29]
3D Models/untitledbaseplate-v10.stl
116.6 x 127.3 x 29.0

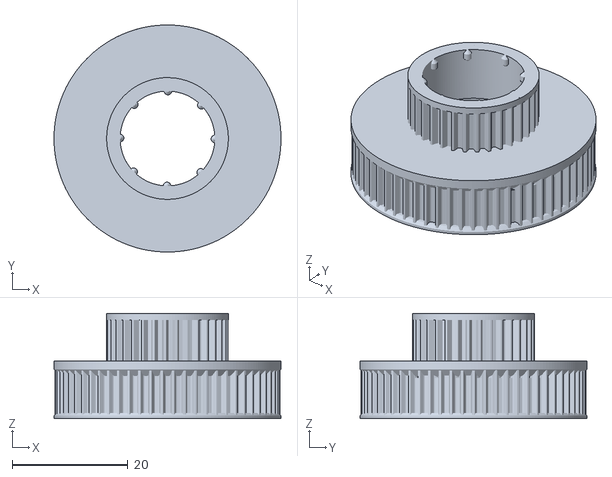
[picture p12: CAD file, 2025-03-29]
3D Models/untitledreduction-v10.stl
39.3 x 39.3 x 18.2

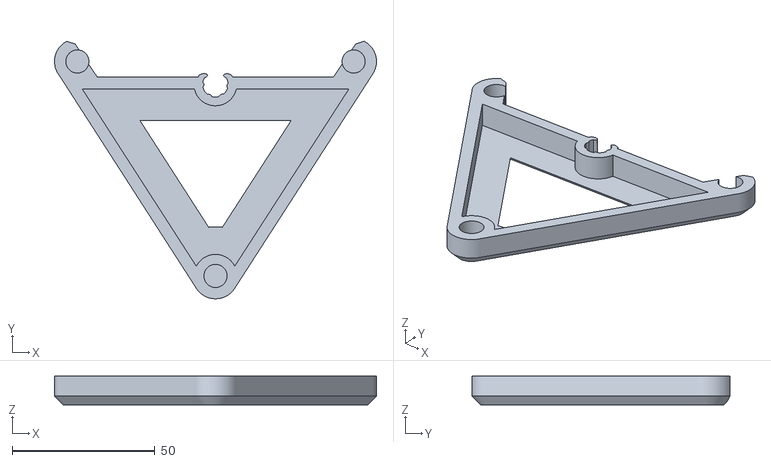
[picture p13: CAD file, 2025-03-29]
3D Models/untitledtop-triangle-v10.stl
112.6 x 90.1 x 10.0

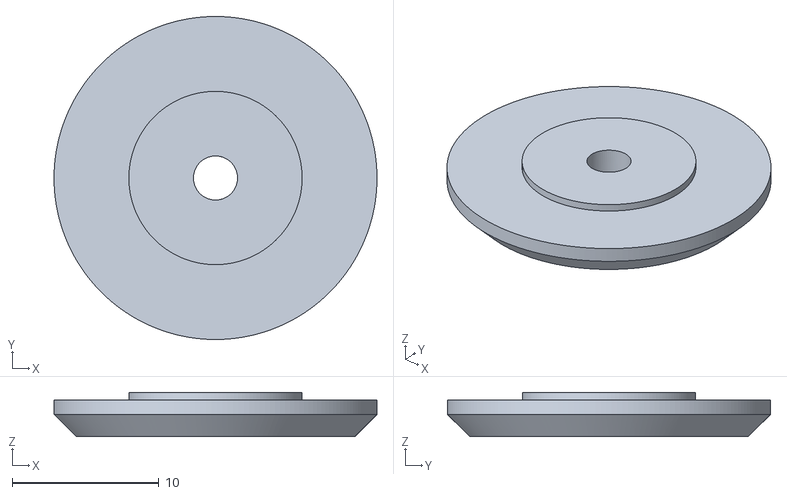
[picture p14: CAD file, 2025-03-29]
3D Models/untitledcap-v10.stl
22.0 x 22.0 x 3.00

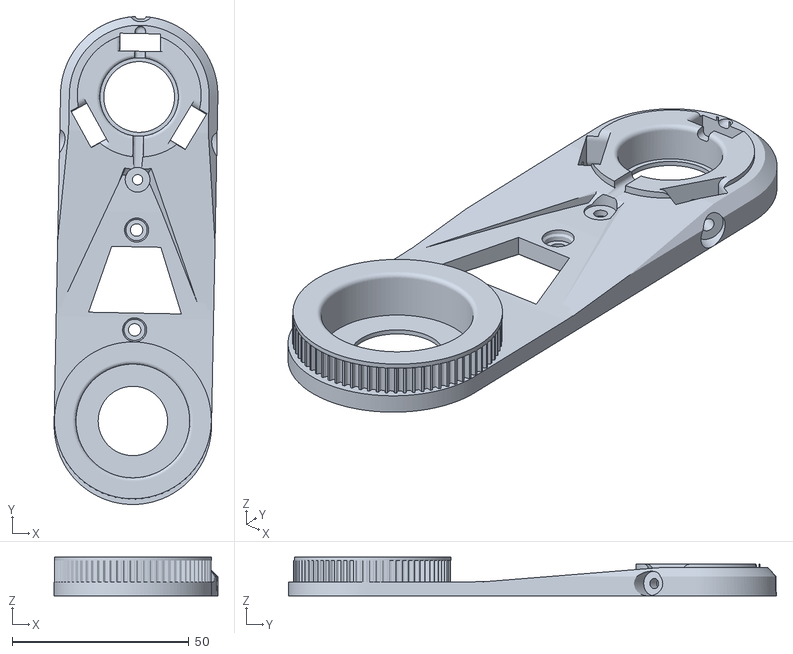
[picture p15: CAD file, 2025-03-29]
3D Models/untitledarm-top-v9.stl
46.3 x 138.0 x 11.0

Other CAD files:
3D Models/untitledgripper-nails-v10.stl

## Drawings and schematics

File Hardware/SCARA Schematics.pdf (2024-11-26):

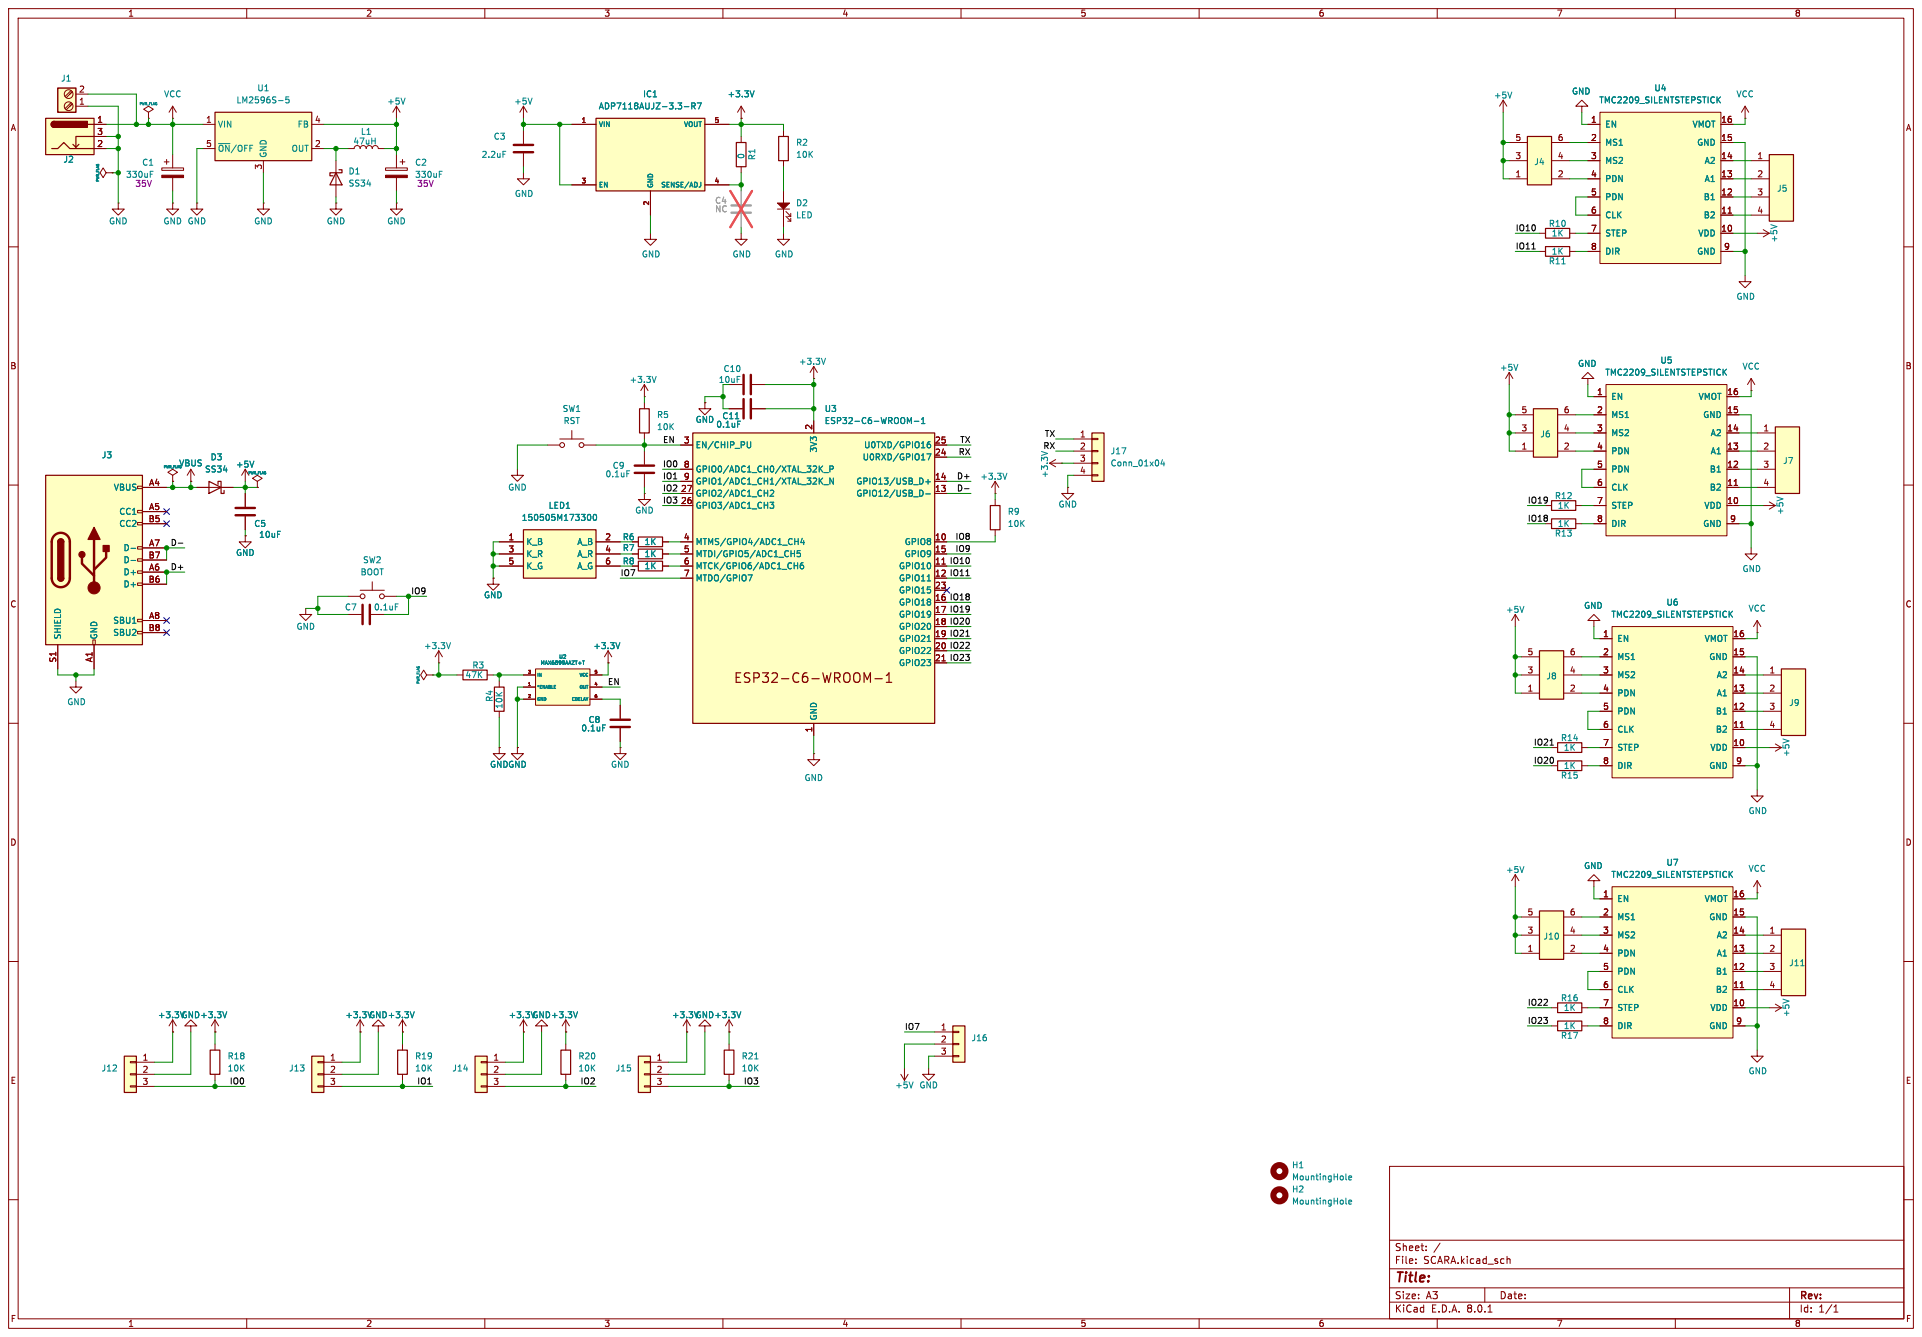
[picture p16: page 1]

2 EN 3 SENSE/ADJ 4 VOUT 5

2 EN 3 SENSE/ADJ 4 VOUT 5C4 NC

2 GPIO22 20 GPIO23 21 GPIO15 23 U0RXD/GPIO17 24 U0TXD/GPIO16 25 GPIO3/ADC1_CH3 26 GPIO2/ADC1_CH2 27 EN/CHIP_PU 3 MTMS/GPIO4/ADC1_CH4 4 MTDI/GPIO5/ADC1_CH5 5 MTCK/GPIO6/ADC1_CH6 6 MTDO/GPIO7 7 GPIO0/ADC1_CH0/XTAL_32K_P 8 GPIO1/ADC1_CH1/XTAL_32K_N 9 U3ESP32-C6-WROOM-1 C11

2 GPIO22 20 GPIO23 21 GPIO15 23 U0RXD/GPIO17 24 U0TXD/GPIO16 25 GPIO3/ADC1_CH3 26 GPIO2/ADC1_CH2 27 EN/CHIP_PU 3 MTMS/GPIO4/ADC1_CH4 4 MTDI/GPIO5/ADC1_CH5 5 MTCK/GPIO6/ADC1_CH6 6 MTDO/GPIO7 7 GPIO0/ADC1_CH0/XTAL_32K_P 8 GPIO1/ADC1_CH1/XTAL_32K_N 9 GND

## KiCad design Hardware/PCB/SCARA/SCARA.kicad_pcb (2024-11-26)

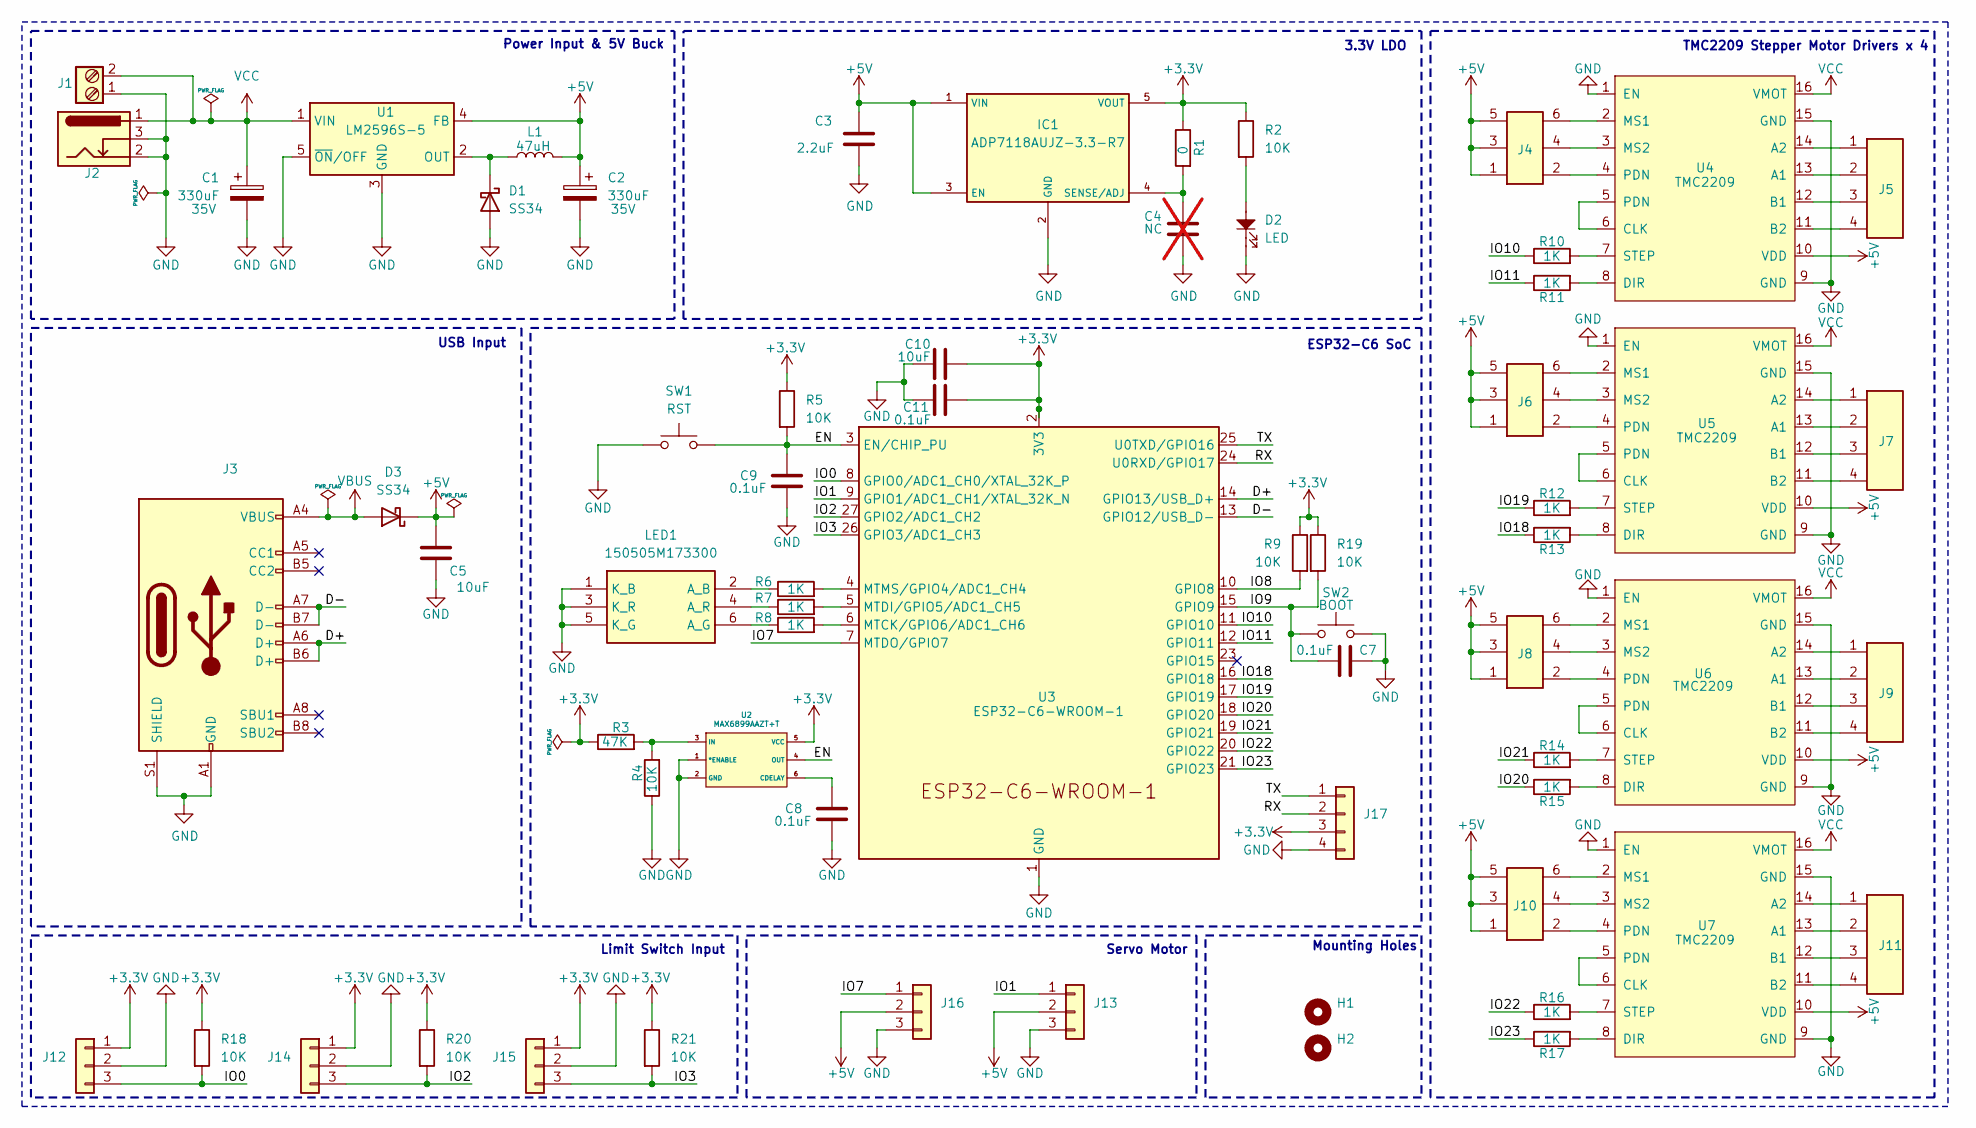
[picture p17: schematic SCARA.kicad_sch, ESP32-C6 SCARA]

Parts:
C1, C2: 330uF; CAP_J-V_10X10P5_RUB; Voltage 35V
C3: 2.2uF; C_0603_1608Metric
C4: NC; C_0603_1608Metric; not fitted
C5, C10: 10uF; C_0805_2012Metric
C7, C8, C9, C11: 0.1uF; C_0603_1608Metric
D1, D3: SS34; D_SMA
D2: LED; LED_0805_2012Metric
H1, H2: MountingHole; MountingHole_2.2mm_M2_Pad
IC1: ADP7118AUJZ-3.3-R7; SOT95P280X100-5N; Mouser Part Number 584-ADP7118AUJZ3.3R7
J1: Screw_Terminal_2_P5.00mm; TerminalBlock_Phoenix_PT-1,5-2-5.0-H_1x02_P5.00mm_Horizontal
J2: Barrel_Jack_Switch; BarrelJack_Kycon_KLDX-0202-xC_Horizontal
J3: USB_C_Receptacle_USB2.0; USB_C_Receptacle_HRO_TYPE-C-31-M-12
J4, J6, J8, J10: Conn_02x03_Top_Bottom; PinHeader_2x03_P2.54mm_Vertical
J5, J7, J9, J11: Conn_01x04; JST_XH_B4B-XH-AM_1x04_P2.50mm_Vertical
J12, J13, J14, J15, J16: Conn_01x03; JST_XH_B3B-XH-AM_1x03_P2.50mm_Vertical
J17: Conn_01x04; JST_EH_B4B-EH-A_1x04_P2.50mm_Vertical
L1: 47uH; L_12x12mm_H8mm
LED1: 150505M173300; Mouser Part Number 710-150505M173300
R1: 0; R_0603_1608Metric
R2, R4, R5, R9, R18, R19, R20, R21: 10K; R_0603_1608Metric
R3: 47K; R_0603_1608Metric
R6, R7, R8, R10, R11, R12, R13, R14, R15, R16, R17: 1K; R_0603_1608Metric
SW1: RST; Tactile 3x4x2mm TS-A010
SW2: BOOT; Tactile 3x4x2mm TS-A010
U1: LM2596S-5; TO-263-5_TabPin3
U2: MAX6899AAZT+T
U3: ESP32-C6-WROOM-1
U4, U5, U6, U7: TMC2209; MODULE_TMC2209_SILENTSTEPSTICK

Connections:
+3.3V: C10.1, C11.1, IC1.5 (VOUT), J12.1, J14.1, J15.1, J17.3, R1.1, R2.1, R3.1, R5.1, R9.1, R18.1, R19.1, R20.1, R21.1, U2.5 (VCC), U3.2 (3V3)
+5V: C2.1, C3.1, C5.1, D3.1 (K), IC1.1 (VIN), IC1.3 (EN), J4.1, J4.3, J4.5, J6.1, J6.3, J6.5, J8.1, J8.3, J8.5, J10.1, J10.3, J10.5, J13.2, J16.2, L1.2, U1.4 (FB), U4.10 (VDD), U5.10 (VDD), U6.10 (VDD), U7.10 (VDD)
/D+: J3.A6 (D+), J3.B6 (D+), U3.14 (GPIO13/USB_D+)
/D-: J3.A7 (D-), J3.B7 (D-), U3.13 (GPIO12/USB_D-)
/EN: C9.1, R5.2, SW1.2, U2.4 (OUT), U3.3 (EN/CHIP_PU)
/IO0: J12.3, R18.2, U3.8 (GPIO0/ADC1_CH0/XTAL_32K_P)
/IO1: J13.1, U3.9 (GPIO1/ADC1_CH1/XTAL_32K_N)
/IO2: J14.3, R20.2, U3.27 (GPIO2/ADC1_CH2)
/IO3: J15.3, R21.2, U3.26 (GPIO3/ADC1_CH3)
/IO7: J16.1, U3.7 (MTDO/GPIO7)
/IO8: R9.2, U3.10 (GPIO8)
/IO9: C7.2, R19.2, SW2.2, U3.15 (GPIO9)
/IO10: R10.1, U3.11 (GPIO10)
/IO11: R11.1, U3.12 (GPIO11)
/IO18: R13.1, U3.16 (GPIO18)
/IO19: R12.1, U3.17 (GPIO19)
/IO20: R15.1, U3.18 (GPIO20)
/IO21: R14.1, U3.19 (GPIO21)
/IO22: R16.1, U3.20 (GPIO22)
/IO23: R17.1, U3.21 (GPIO23)
/RX: J17.2, U3.24 (U0RXD/GPIO17)
/TX: J17.1, U3.25 (U0TXD/GPIO16)
GND: C1.2, C2.2, C3.2, C4.2, C5.2, C7.1, C8.2, C9.2, C10.2, C11.2, D1.2 (A), D2.1, IC1.2 (GND), J1.1, J2.2, J2.3, J3.A1 (GND), J3.A12 (GND), J3.B1 (GND), J3.B12 (GND), J3.S1 (SHIELD), J12.2, J13.3, J14.2, J15.2, J16.3, J17.4, LED1.1 (K_B), LED1.3 (K_R), LED1.5 (K_G), R4.1, SW1.1, SW2.1, U1.3 (GND), U1.5 (~ON/OFF), U2.1 (*ENABLE), U2.2 (GND), U3.1 (GND), U3.28 (GND), U3.29 (GND), U4.1 (EN), U4.9 (GND), U4.15 (GND), U5.1 (EN), U5.9 (GND), U5.15 (GND), U6.1 (EN), U6.9 (GND), U6.15 (GND), U7.1 (EN), U7.9 (GND), U7.15 (GND)
unnamed: D1.1 (K), L1.1, U1.2 (OUT)
unnamed: D2.2, R2.2
unnamed: C4.1, IC1.4 (SENSE/ADJ), R1.2
unnamed: J4.2, U4.4 (PDN)
unnamed: J4.4, U4.3 (MS2)
unnamed: J4.6, U4.2 (MS1)
unnamed: J5.1, U4.14 (A2)
unnamed: J5.2, U4.13 (A1)
unnamed: J5.3, U4.12 (B1)
unnamed: J5.4, U4.11 (B2)
unnamed: J6.2, U5.4 (PDN)
unnamed: J6.4, U5.3 (MS2)
unnamed: J6.6, U5.2 (MS1)
unnamed: J7.1, U5.14 (A2)
unnamed: J7.2, U5.13 (A1)
unnamed: J7.3, U5.12 (B1)
unnamed: J7.4, U5.11 (B2)
unnamed: J8.2, U6.4 (PDN)
unnamed: J8.4, U6.3 (MS2)
unnamed: J8.6, U6.2 (MS1)
unnamed: J9.1, U6.14 (A2)
unnamed: J9.2, U6.13 (A1)
unnamed: J9.3, U6.12 (B1)
unnamed: J9.4, U6.11 (B2)
unnamed: J10.2, U7.4 (PDN)
unnamed: J10.4, U7.3 (MS2)
unnamed: J10.6, U7.2 (MS1)
unnamed: J11.1, U7.14 (A2)
unnamed: J11.2, U7.13 (A1)
unnamed: J11.3, U7.12 (B1)
unnamed: J11.4, U7.11 (B2)
unnamed: LED1.2 (A_B), R6.1
unnamed: LED1.6 (A_G), R8.1
unnamed: LED1.4 (A_R), R7.1
unnamed: C8.1, U2.6 (CDELAY)
unnamed: R3.2, R4.2, U2.3 (IN)
unnamed: R8.2, U3.6 (MTCK/GPIO6/ADC1_CH6)
unnamed: R7.2, U3.5 (MTDI/GPIO5/ADC1_CH5)
unnamed: R6.2, U3.4 (MTMS/GPIO4/ADC1_CH4)
unnamed: U4.5 (PDN), U4.6 (CLK)
unnamed: R11.2, U4.8 (DIR)
unnamed: R10.2, U4.7 (STEP)
unnamed: U5.5 (PDN), U5.6 (CLK)
unnamed: R13.2, U5.8 (DIR)
unnamed: R12.2, U5.7 (STEP)
unnamed: U6.5 (PDN), U6.6 (CLK)
unnamed: R15.2, U6.8 (DIR)
unnamed: R14.2, U6.7 (STEP)
unnamed: U7.5 (PDN), U7.6 (CLK)
unnamed: R17.2, U7.8 (DIR)
unnamed: R16.2, U7.7 (STEP)
VBUS: D3.2 (A), J3.A4 (VBUS), J3.A9 (VBUS), J3.B4 (VBUS), J3.B9 (VBUS)
VCC: C1.1, J1.2, J2.1, U1.1 (VIN), U4.16 (VMOT), U5.16 (VMOT), U6.16 (VMOT), U7.16 (VMOT)

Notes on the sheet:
TMC2209 Stepper Motor Drivers x 4
Power Input & 5V Buck
ESP32-C6 SoC
Servo Motor
3.3V LDO
USB Input
Limit Switch Input
Mounting Holes

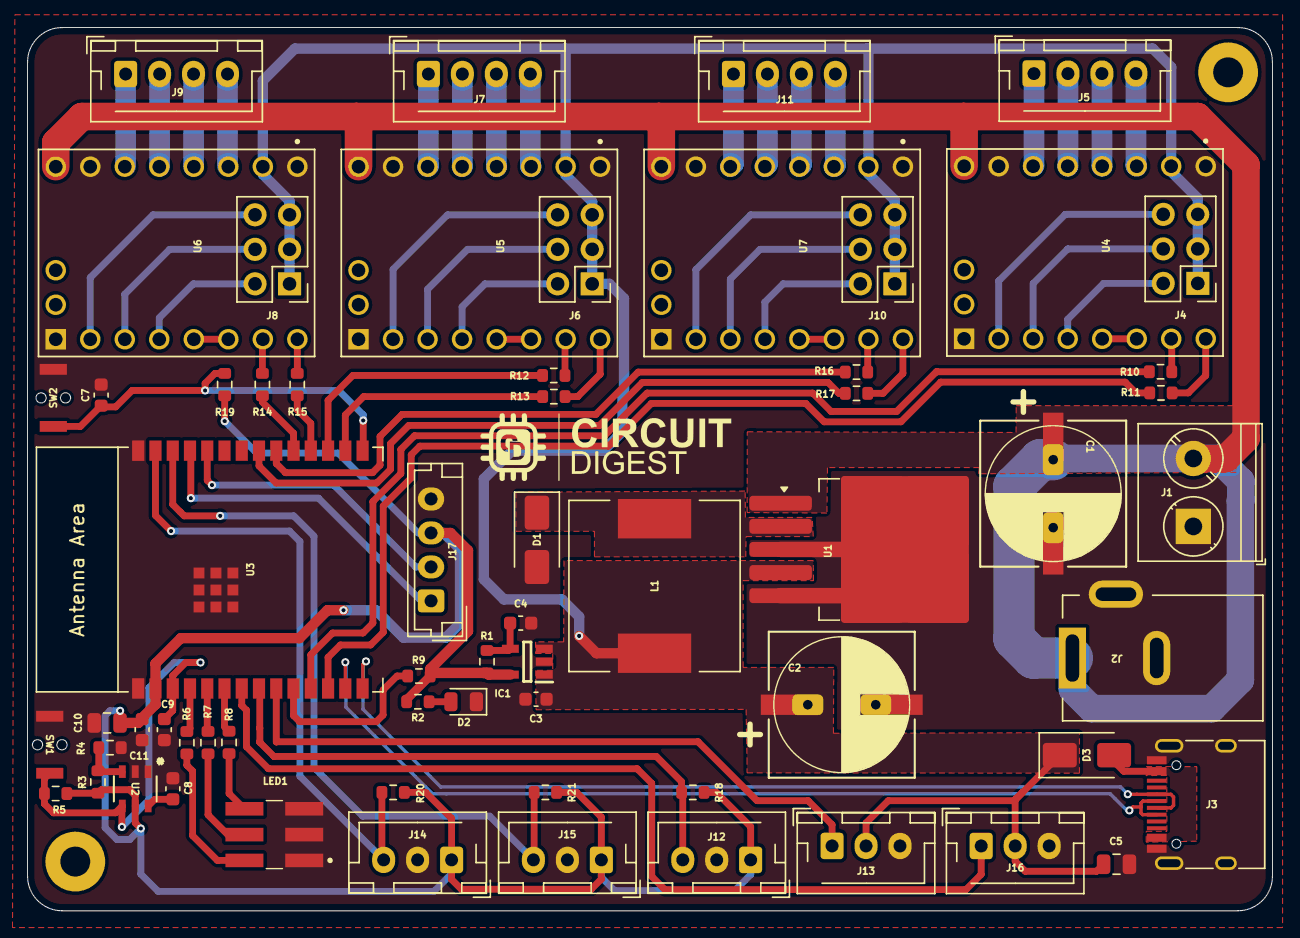
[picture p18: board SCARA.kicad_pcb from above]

Board: 2 copper layers, 91.6 x 65.0 mm, 65 parts (0 on the bottom side), 76 nets.

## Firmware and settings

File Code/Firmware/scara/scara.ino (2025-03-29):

/*
 * Project Name: Scara Robot
 * Project Brief: ESP32-C6 based SCARA RBOT.
 * Author: Jobit Joseph @ https://github.com/jobitjoseph
 * IDE: Arduino IDE 2.x.x
 * Arduino Core: ESP32 Arduino Core V 3.0.5
 *
 * Copyright © Jobit Joseph
 * Copyright © Semicon Media Pvt Ltd
 * Copyright © Circuitdigest.com
 * 
 * This code is licensed under the following conditions:
 *
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
 * 2. Commercial Use:
 * For any commercial use of this software, you must obtain a separate license
 * from the original author. Contact the author for permissions or licensing
 * options before using this software for commercial purposes.
 *
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
 * Author: Jobit Joseph
 * Date: 18 October 2024
 *
 * For commercial use or licensing requests, please contact [jobitjoseph1@gmail.com].
 */
#include <AccelStepper.h>
#include <ESP32Servo.h>
#include <HardwareSerial.h>

#define RX_PIN 17
#define TX_PIN 16

#define GRIPPER_PIN 7  // Pin for the servo controlling the gripper
#define WRIST_PIN 1    // Pin for the servo controlling wrist rotation

// Define the stepper motors and the pins they will use
AccelStepper stepper1(1, 21, 20); // (Type:driver, STEP, DIR)
AccelStepper stepper2(1, 19, 18);
AccelStepper stepper3(1, 22, 23);

Servo gripperServo;  // create servo object to control a servo
Servo wristServo;    // Servo object for the wrist rotation

// Variables for kinematics
double L1 = 91.6; // Length of arm 1
double L2 = 95.2; // Length of arm 2
double theta1, theta2, phi, z;

const float theta1AngleToSteps = 14.55;  // Conversion factor for theta1
const float theta2AngleToSteps = 11.43;  // Conversion factor for theta2
const float zAngleToSteps = 400;             // Conversion factor for phi
const int gripperCloseAngle = 140;
const int gripperOpenAngle = 100;

void setup() {
    Serial.begin(115200); // USB communication for debugging

    // Stepper motors max speed and acceleration
    stepper1.setMaxSpeed(4000);
    stepper1.setAcceleration(2000);
    stepper2.setMaxSpeed(4000);
    stepper2.setAcceleration(2000);
    stepper3.setMaxSpeed(4000);
    stepper3.setAcceleration(2000);

    gripperServo.attach(GRIPPER_PIN);
    gripperServo.write(gripperOpenAngle); // Open gripper by default

    wristServo.attach(WRIST_PIN); // Pin for wrist control
    wristServo.write(90); // Default wrist angle

    delay(1000);
    Serial.println("Initialization completed");
}

void loop() {
    if (Serial.available()) {
        String command = Serial.readStringUntil('\n');
        command.trim();
        executeCommand(command);
    }
}

void executeCommand(String command) {
    // Home command
    if (command.equalsIgnoreCase("home")) {
        homing();
    }
    // Move command in format: move x y z gripper gripperz speed accel
    else if (command.startsWith("move")) {
        int x, y, z;
        if (sscanf(command.c_str(), "move %d %d %d", &x, &y, &z) == 3) {
            moveToPosition(x, y, z);
        } else {
            Serial.println("Invalid move command format. Use: move x y z gripper gripperz speed accel");
        }
    }
    else if (command.startsWith("gripperz")) {
        int gripperZ;
        if (sscanf(command.c_str(), "gripperz %d", &gripperZ) == 1) {
            setGripperZ(gripperZ);
        } else {
            Serial.println("Invalid acceleration command format. Use: set_accel <accel>");
        }
    }
    // Set speed command
    else if (command.startsWith("set_speed")) {
        int speed;
        if (sscanf(command.c_str(), "set_speed %d", &speed) == 1) {
            setSpeedAllMotors(speed);
        } else {
            Serial.println("Invalid speed command format. Use: set_speed <speed>");
        }
    }
    // Set acceleration command
    else if (command.startsWith("set_accel")) {
        int accel;
        if (sscanf(command.c_str(), "set_accel %d", &accel) == 1) {
            setAccelerationAllMotors(accel);
        } else {
            Serial.println("Invalid acceleration command format. Use: set_accel <accel>");
        }
    }
    // Stop command
    else if (command.equalsIgnoreCase("stop")) {
        stopAllMotors();
    }
    // Open gripper command
    else if (command.equalsIgnoreCase("open_gripper")) {
        gripperServo.write(gripperOpenAngle); // Open gripper
    }
    // Close gripper command
    else if (command.equalsIgnoreCase("close_gripper")) {
        gripperServo.write(gripperCloseAngle); // Close gripper
    }
    // Unknown command
    else {
        Serial.println("Unknown command");
    }
}

// Function to move to position
void moveToPosition(int x, int y, int z) {
  
    stepper1.moveTo(x * theta1AngleToSteps);
    stepper2.moveTo(y * theta2AngleToSteps);
    stepper3.moveTo(z * zAngleToSteps);
    
    while (stepper1.isRunning() || stepper2.isRunning() || stepper3.isRunning()) {
        stepper1.run();
        stepper2.run();
        stepper3.run();
    }
}

void setGripperZ(int gripperZ){
wristServo.write(gripperZ); // Set wrist position
}

// Function to set speed for all motors
void setSpeedAllMotors(int speed) {
    stepper1.setSpeed(speed);
    stepper2.setSpeed(speed);
    stepper3.setSpeed(speed);
    Serial.print("Speed set for all motors: ");
    Serial.println(speed);
}

// Function to set acceleration for all motors
void setAccelerationAllMotors(int accel) {
    stepper1.setAcceleration(accel);
    stepper2.setAcceleration(accel);
    stepper3.setAcceleration(accel);
    Serial.print("Acceleration set for all motors: ");
    Serial.println(accel);
}

// Function to stop all motors
void stopAllMotors() {
    stepper1.stop();
    stepper2.stop();
    stepper3.stop();
    Serial.println("Motors stopped");
}

// Function for homing the robot
void homing() {
    // Implement homing logic here (e.g., move to a known position)
    Serial.println("Homing all motors");
    // Example homing code: move to the origin
    stepper1.moveTo(0);
    stepper2.moveTo(0);
    stepper3.moveTo(0);
    while (stepper1.isRunning() || stepper2.isRunning() || stepper3.isRunning()) {
        stepper1.run();
        stepper2.run();
        stepper3.run();
    }
    Serial.println("Homing completed");
}

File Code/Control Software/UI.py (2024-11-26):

import serial
import tkinter as tk
from tkinter import ttk, messagebox

# Configure the serial port
ser = serial.Serial('COM7', 115200, timeout=1)

# Variable to track gripper state (1: open, 0: close)
gripper_state = 0
recording = False
movements = []

def send_command(command):
    try:
        ser.write(command.encode())
        print(f"Sent: {command.strip()}")  # Debug: print sent command
        log_message(f"Command Sent: {command.strip()}")
    except Exception as e:
        log_message(f"Failed to send command: {e}", is_error=True)

def move_robot(x, y, z):
    x_rounded = round(x)
    y_rounded = round(y)
    z_rounded = round(z)
    command = f"move {x_rounded} {y_rounded} {z_rounded}\n"
    send_command(command)

    # Record the movement if recording is active
    if recording:
        movements.append(("move", x_rounded, y_rounded, z_rounded))

def set_gripper_z(gripperz):
    gripperz_rounded = round(float(gripperz))
    command = f"gripperz {gripperz_rounded}\n"
    send_command(command)

    # Record the gripper Z movement if recording is active
    if recording:
        movements.append(("gripperz", gripperz_rounded))

def toggle_gripper():
    global gripper_state
    if gripper_state == 0:
        command = "open_gripper\n"
        gripper_state = 1
        gripper_button.config(text="Gripper: Open")
        log_message("Gripper opened.")
    else:
        command = "close_gripper\n"
        gripper_state = 0
        gripper_button.config(text="Gripper: Closed")
        log_message("Gripper closed.")
    send_command(command)

    # Record the gripper open/close state if recording is active
    if recording:
        movements.append(("gripper_state", gripper_state))

def set_speed():
    speed = int(speed_entry.get())
    if 100 <= speed <= 5000:
        command = f"set_speed {speed}\n"
        send_command(command)
        log_message(f"Speed set to: {speed}")
    else:
        log_message("Speed value must be between 100 and 5000.", is_error=True)

def set_accel():
    accel = int(accel_entry.get())
    if 100 <= accel <= 5000:
        command = f"set_accel {accel}\n"
        send_command(command)
        log_message(f"Acceleration set to: {accel}")
    else:
        log_message("Acceleration value must be between 100 and 5000.", is_error=True)

def stop_robot():
    command = "stop\n"
    send_command(command)
    log_message("Robot stopped.")

# Function to update label text based on slider value
def update_label(slider, label):
    label.config(text=f"{label.cget('text').split(':')[0]}: {round(slider.get())}")

# Function to log messages in the feedback area
def log_message(message, is_error=False):
    if is_error:
        feedback_area.config(fg="red")
    else:
        feedback_area.config(fg="black")
    feedback_area.insert(tk.END, message + "\n")
    feedback_area.see(tk.END)  # Scroll to the end

# Modern UI design with ttk widgets
root = tk.Tk()
root.title("SCARA Robot Control")
root.geometry("800x500")  # Landscape window size

# Create a main frame
main_frame = ttk.Frame(root)
main_frame.pack(fill=tk.BOTH, expand=True)

# Robot Movement Section
robot_frame = ttk.LabelFrame(main_frame, text="Robot Movement", padding=(10, 10))
robot_frame.pack(side=tk.LEFT, padx=10, pady=10, fill='both', expand=True)

def update_position(event=None):
    move_robot(slider_x.get(), slider_y.get(), slider_z.get())

# X Position Control
x_frame = ttk.Frame(robot_frame)
x_frame.pack(pady=5)
slider_x = ttk.Scale(x_frame, from_=-150, to=150, orient=tk.HORIZONTAL, length=250)
slider_x.grid(row=0, column=0)
x_label = ttk.Label(x_frame, text="X Position: 0")
x_label.grid(row=1, column=0)
slider_x.bind("<Motion>", lambda event: update_label(slider_x, x_label))
slider_x.bind("<ButtonRelease-1>", update_position)

# Y Position Control
y_frame = ttk.Frame(robot_frame)
y_frame.pack(pady=5)
slider_y = ttk.Scale(y_frame, from_=-700, to=700, orient=tk.HORIZONTAL, length=250)
slider_y.grid(row=0, column=0)
y_label = ttk.Label(y_frame, text="Y Position: 0")
y_label.grid(row=1, column=0)
slider_y.bind("<Motion>", lambda event: update_label(slider_y, y_label))
slider_y.bind("<ButtonRelease-1>", update_position)

# Z Position Control
z_frame = ttk.Frame(robot_frame)
z_frame.pack(pady=5)
slider_z = ttk.Scale(z_frame, from_=0, to=80, orient=tk.HORIZONTAL, length=250)
slider_z.grid(row=0, column=0)
z_label = ttk.Label(z_frame, text="Z Position: 0")
z_label.grid(row=1, column=0)
slider_z.bind("<Motion>", lambda event: update_label(slider_z, z_label))
slider_z.bind("<ButtonRelease-1>", update_position)

# Gripper Z Control
gripperz_frame = ttk.Frame(robot_frame)
gripperz_frame.pack(pady=5)
slider_gripper_z = ttk.Scale(gripperz_frame, from_=0, to=180, orient=tk.HORIZONTAL, length=250)
slider_gripper_z.grid(row=0, column=0)
gripperz_label = ttk.Label(gripperz_frame, text="Gripper Z Position: 0")
gripperz_label.grid(row=1, column=0)
slider_gripper_z.bind("<Motion>", lambda event: update_label(slider_gripper_z, gripperz_label))
slider_gripper_z.bind("<ButtonRelease-1>", lambda event: set_gripper_z(slider_gripper_z.get()))

# Manual Input Section
manual_frame = ttk.LabelFrame(main_frame, text="Manual Input", padding=(10, 10))
manual_frame.pack(side=tk.LEFT, padx=10, pady=10, fill='both', expand=True)

# Position control textboxes and buttons for each axis
def set_position(axis):
    try:
        position = int(position_entries[axis].get())
        if axis == 'x':
            slider_x.set(position)
        elif axis == 'y':
            slider_y.set(position)
        elif axis == 'z':
            slider_z.set(position)
        move_robot(slider_x.get(), slider_y.get(), slider_z.get())
    except ValueError:
        log_message("Please enter a valid integer.", is_error=True)

position_entries = {}
for axis in ['x', 'y', 'z']:
    frame = ttk.Frame(manual_frame)
    frame.pack(pady=5)
    label = ttk.Label(frame, text=f"{axis.upper()} Position:")
    label.grid(row=0, column=0)
    entry = ttk.Entry(frame, width=10)
    entry.grid(row=0, column=1)
    position_entries[axis] = entry
    button = ttk.Button(frame, text="Set", command=lambda a=axis: set_position(a))
    button.grid(row=0, column=2)

# Speed Control
speed_frame = ttk.Frame(manual_frame)
speed_frame.pack(pady=5)
ttk.Label(speed_frame, text="Speed:").grid(row=0, column=0)
speed_entry = ttk.Entry(speed_frame, width=10)
speed_entry.insert(0, "500")  # Default value
speed_entry.grid(row=0, column=1)
ttk.Button(speed_frame, text="Set Speed", command=set_speed).grid(row=0, column=2)

# Acceleration Control
accel_frame = ttk.Frame(manual_frame)
accel_frame.pack(pady=5)
ttk.Label(accel_frame, text="Acceleration:").grid(row=0, column=0)
accel_entry = ttk.Entry(accel_frame, width=10)
accel_entry.insert(0, "500")  # Default value
accel_entry.grid(row=0, column=1)
ttk.Button(accel_frame, text="Set Acceleration", command=set_accel).grid(row=0, column=2)
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
